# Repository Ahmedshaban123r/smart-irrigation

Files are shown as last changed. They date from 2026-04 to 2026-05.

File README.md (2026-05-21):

# An AI-Augmented Cyber-Physical Smart Precision Irrigation System

> **Course:** CIE-349 / CIE-408 — Embedded Systems (Spring 2026)
> **Institution:** Zewail City of Science and Technology
> **Program:** Communications and Information Engineering (CIE)
> **Repository status:** active development — see `STREAMS.md` for the team ↔ folder ↔ gate mapping.

---

## 1. Abstract

This repository contains the full engineering artefacts of a cyber-physical
precision-irrigation platform that couples real-time embedded control, networked
IoT telemetry, a cross-platform mobile human–machine interface, and on-device
computer-vision inference. The system continuously senses the soil-water,
electrical, thermal, and tank-level state of a two-plant test bench, performs a
safety-critical evaluation against a hysteresis-protected fault model, and
actuates a pump and a Cartesian gantry to deliver water on a per-plant basis.
A Raspberry Pi 4 attached to the same UART bus performs convolutional-neural-network
inference on plant images captured by a CSI camera, classifies disease state into
six clinical categories, and serialises both telemetry and inference results to a
Firebase Realtime Database (RTDB). A Flutter mobile client subscribes to the same
RTDB, rendering live sensor streams, AI detections, and an operator command surface
(pump toggle, gantry positioning, mode switching, emergency stop). The project
demonstrates the integration of MCU-class deterministic control, edge-class neural
inference, cloud-class persistence, and a touch-class user interface within a
single, gate-driven engineering process.

---

## 2. System Overview

| Subsystem | Hardware | Toolchain | Role |
|---|---|---|---|
| Real-time controller | PIC16F877A-I/P (8 MHz crystal) | MPLAB X IDE + XC8 v2.36 | Deterministic sensing, safety FSM, motion control, UART arbitration |
| Wi-Fi pump actuator | ESP8266 NodeMCU v3 | Arduino core, `Firebase_ESP_Client` | Wireless pump relay triggered by Firebase commands from the app / Pi |
| Edge AI + IoT gateway | Raspberry Pi 4 Model B (4 GB) | Python 3.11, `firebase-admin`, `pyserial`, TensorFlow Lite | Image capture, CNN inference, UART ↔ Firebase bridge |
| Cloud persistence | Firebase RTDB + Cloud Storage | Firebase JS/Admin SDK | Telemetry store, command queue, image hosting |
| Mobile HMI | Android / iOS | Flutter (Dart 3) + Material 3 | Dashboard, actuator control, AI monitor, alerts, voice command |
| Mechanical | Custom 3D-printed gantry | OpenSCAD source + STL | Linear motion, instrumentation mount, electronics enclosure |

> **Note on the actuator topology.** The pump can be driven through two
> independent paths. The **wired path** routes commands over UART
> (App → Firebase → Pi → PIC → relay on `RD0`) and is gated by the on-board
> safety FSM. The **wireless path** routes commands directly to an ESP8266
> NodeMCU that polls Firebase at `/esp/pump/state` and toggles its own relay
> on `D1` for a fixed 5-second cycle. Both paths can coexist on the same
> physical pump or drive separate solenoids; the ESP path is intended as a
> fast, low-latency override for app-initiated watering and for resilience
> when the Pi bridge is offline.

---

## 3. High-Level Architecture

```
┌──────────────────────────────────────────────────────────────────────────────┐
│                          PHYSICAL / ANALOG DOMAIN                            │
│                                                                              │
│  Soil moisture (cap.)   ACS712-05B   DHT11   HC-SR04   Limit SW   E-Stop SW  │
│        │                    │          │        │          │         │       │
│        ▼                    ▼          ▼        ▼          ▼         ▼       │
│   ┌────────────────────────────────────────────────────────────────────┐    │
│   │                       PIC16F877A (8 MHz)                           │    │
│   │   MCAL: ADC | GPIO | USART | TIMER0 | Interrupt Manager            │    │
│   │   HAL : Soil | Current | Humidity | Ultrasonic | LCD | LED | ...   │    │
│   │   APP : Safety FSM | Irrigation Sequencer | Comms | Main scheduler │    │
│   └────────────────────────────────────────────────────────────────────┘    │
│        │                    │                   │           │                │
│        ▼                    ▼                   ▼           ▼                │
│  Pump relay (12 V)     A4988 + NEMA17       Buzzer +     16×2 LCD            │
│  (wired path, RD0)     stepper gantry       LEDs                             │
└──────────────────────────────┬───────────────────────────────────────────────┘
                               │ UART 9600-8N1
                               │ (custom framed protocol, §6)
                               ▼
┌──────────────────────────────────────────────────────────────────────────────┐
│                       RASPBERRY PI 4 (edge gateway)                          │
│   capture_and_infer.sh  →  libcamera  →  TFLite (MobileNetV2 INT8)           │
│   pi_controller.py      :  serial RX/TX  ⇄  Firebase RTDB + Storage          │
└──────────────────────────────┬───────────────────────────────────────────────┘
                               │ HTTPS / WebSocket (Firebase SDK)
                               ▼
┌──────────────────────────────────────────────────────────────────────────────┐
│                       FIREBASE  (RTDB + Storage)                             │
│   /sensors  /status  /commands  /ai  /alerts  /esp/pump/state                │
└──────┬───────────────────────┬───────────────────────────────────────────────┘
       │ Firebase listener     │ 1 Hz poll on /esp/pump/state
       ▼                       ▼
┌─────────────────────────┐   ┌─────────────────────────────────────────────┐
│  FLUTTER MOBILE CLIENT  │   │           ESP8266 NodeMCU v3                │
│  (Android / iOS)        │   │   Wi-Fi → Firebase_ESP_Client                │
│  Landing → Dashboard →  │   │   D1 relay → wireless pump (5 s cycle,       │
│  Controls → AI Monitor  │   │            self-clears node on completion)   │
│  → Alerts (STT mic)     │   └─────────────────────────────────────────────┘
└─────────────────────────┘
```

**Two actuator paths to the pump:**

* **Wired path** — Flutter writes a `commands/pump` node → the Pi bridge
  consumes it → encodes a `0xBB 0x04` UART frame → PIC validates against the
  safety FSM → drives the relay on `RD0` for `PUMP_ON_TICKS × 100 ms`.
* **Wireless path** — Flutter writes `/esp/pump/state = "ON"` → the ESP8266
  picks it up within ≤ 1 s on its polling loop → energises its own relay on
  `D1` for `PUMP_ON_MS = 5000 ms` → resets the node to `"OFF"`.

---

## 4. Repository Layout

```
smart-irrigation/
├── pic-firmware/         PIC16F877A MPLAB X project (Stream A)
│   ├── MCAL/             Microcontroller-abstraction layer (ADC, USART, GPIO, TIMER0)
│   ├── HAL/              Hardware-abstraction layer (LCD, sensors, motor, relay, …)
│   ├── SERVICES/         Reusable services (STD_TYPES, BIT_MATH, Delay)
│   ├── APP/              Application layer (Safety, Comms, Irrigation, MyProject)
│   ├── include/          Cross-module headers (frame defs, pin maps)
│   ├── config.h          Central configuration (clock, thresholds, pin map, timing)
│   └── cmake/, _build/   Out-of-tree build helpers
│
├── esp-firmware/         ESP8266 NodeMCU pump actuator (Stream C)
│   └── esp.ino           Arduino sketch: Wi-Fi + Firebase polling + relay
│
├── pi-script/            Raspberry Pi bridge daemon (Stream B)
│   ├── pi_controller.py  UART ⇄ Firebase main bridge
│   ├── handshake.py      Boot-time handshake validator
│   ├── bidir_test.py     Loopback UART self-test
│   ├── test_firebase.py  RTDB connectivity test
│   ├── irrigation.service systemd unit (auto-start on boot)
│   └── export.json       RTDB schema snapshot (reference)
│
├── pi-ai/                Inference + camera layer (Stream B)
│   ├── Capture_camera/   libcamera capture + invocation script
│   ├── Irrigation system/Docker_files  Containerised inference runtime
│   ├── inference/        Daemon stubs (TFLite runner)
│   └── protocols/        Action-protocol packet generators
│
├── ml-pipeline/          Model training + export (Stream B)
│   ├── notebooks/Model (1).ipynb   MobileNetV2 fine-tune + INT8 quantisation
│   ├── dataset/          Dataset retrieval and augmentation scripts
│   └── models/           TFLite artefacts + label map + model card
│
├── flutter-app/          Mobile HMI (Stream C)
│   ├── lib/services/     firebase_service, stt_service, notification_service
│   ├── lib/screens/      Landing, Dashboard, Controls, AI Monitor, Alerts
│   ├── lib/widgets/      SensorCard, DetectionCard, StatusBadge, mic button, …
│   ├── lib/models/       protocol_definition.dart
│   ├── lib/theme/        Material 3 theme (greenDeep ↔ greenPale palette)
│   └── android/, ios/    Platform projects
│
├── mechanical/           CAD + STL artefacts (Stream D)
│   ├── cad/              OpenSCAD source (6 printed parts + assembly)
│   ├── stl/              Print-ready exports
│   └── print-settings/   Slicer profiles
│
├── Report and Feasibilty Study/  Course deliverables
├── app-release.apk       Latest Android build (for evaluator side-load)
├── default.hex           Latest PIC HEX (golden image)
├── README.md             ← this file
└── STREAMS.md            Team ↔ folder ↔ gate criteria mapping
```

---

## 5. PIC16F877A Firmware — Architecture

The firmware adopts a strict four-layer architecture inspired by AUTOSAR’s
classic separation of concerns. Each layer depends only on the layer immediately
below it, and inter-module access is mediated by explicit `*_interface.h`
contracts.

```
┌─────────────────────────────────────────────────────────────┐
│  APP/    Safety FSM · Irrigation sequencer · Comms · main  │
├─────────────────────────────────────────────────────────────┤
│  HAL/    LCD · Motor · Relay · Soil · Current · Humidity · │
│          Ultrasonic · LED · Buzzer · Button · Fan · Temp   │
├─────────────────────────────────────────────────────────────┤
│  MCAL/   ADC · USART · GPIO · TIMER0 · Interrupt Manager   │
├─────────────────────────────────────────────────────────────┤
│  SERVICES/  STD_TYPES · BIT_MATH · Delay                   │
└─────────────────────────────────────────────────────────────┘
```

### 5.1 Build configuration

| Parameter | Value |
|---|---|
| MCU | PIC16F877A-I/P (DIP-40) |
| Oscillator | HS, 8 MHz external crystal (with 22 pF load caps) |
| Compiler | Microchip XC8 v2.36 (free mode) |
| IDE | MPLAB X IDE v6.x |
| Programmer | PICkit 3 / PICkit 4 (ICSP) |
| Code memory used | see `_build/` after compilation |
| Power | 5 V regulated, common ground with relay-isolated 12 V rail |

Configuration fuses are declared at the top of `APP/MyProject.c`:
`FOSC=HS`, `WDTE=OFF`, `PWRTE=ON`, `BOREN=ON`, `LVP=OFF`, `CPD=OFF`,
`WRT=OFF`, `CP=OFF`. All build-time tunables live in `pic-firmware/config.h`
(thresholds, pin map, baud divisor, tick periods, microstep counts).

### 5.2 Scheduler model

`APP/MyProject.c` provides two co-existing top-level applications gated by
`#if` blocks:

* **Production main (`Section 1`)** — full pipeline. Cooperative super-loop
  with a 100 ms tick (`__delay_ms(100)`). Soft-real-time periods:
  * Sensor scan: every 2 s (`SENSOR_PERIOD_TICKS = 20`)
  * Auto irrigation cycle: every 5 min (`IRRIG_PERIOD_TICKS = 3000`)
  * Pi handshake gate at boot before entering the loop.
* **Debug main (`Section 2`)** — sensor + photo pipeline without the 5-min
  timer or handshake gate. The carriage bounces between plant 0 (3 cm from
  home) and plant 1 (13 cm). After each move the firmware reads every sensor,
  emits a `SENSORS` packet and an `AT_PLANT` packet, then idles 20 s while the
  Pi captures and uploads an image. Sensor pages are paged onto the LCD every
  4 s during the wait.

The two sections allow bring-up, debug, and demo without recompiling against
two different code trees.

### 5.3 Safety model

The `APP/Safety` module owns a per-channel hysteresis FSM with three states
per channel: **CLEAR → WARN → ACTION (locked)**. Each channel exposes an
independent set of thresholds in `config.h`:

| Channel | Sensor | Warn | Action | Clear | Action consequence |
|---|---|---|---|---|---|
| Soil over-saturation | Capacitive soil (RA0/AN0) | 80 % | 90 % | 75 % | Pump OFF + system lockout |
| Over-temperature | DHT11 (RB0) | 55 °C | 70 °C | 50 °C | Pump + stepper OFF, fan ON, lockout |
| Over-current | ACS712-05B (RA2/AN2) | 3 500 mA | 4 500 mA | 3 000 mA | Full actuator OFF + lockout |
| Dry-run (low tank) | HC-SR04 (RC3 trig / RB1 echo) | 5 cm | 2 cm | 6 cm | Pump OFF + lockout |

Visual / audible annunciation is bound to the FSM state: amber LED (RE1) and
buzzer (RB2) pulse in `WARN`; red LED (RE2) latches in `ACTION`. A lockout is
cleared only when *all* channels return to `CLEAR`.

**Command-priority arbitration** (highest to lowest):
`Safety lockout` ▶ `Hardware E-stop (RB4)` ▶ `App E-stop` ▶ `AI protocol` ▶
`App manual command` ▶ `Scheduled auto cycle`.

### 5.4 Motion control

`HAL/Motor` drives an A4988 stepper driver (1/16 microstepping, MS1/MS2/MS3
tied high externally) connected to a NEMA17 (JK42HS40) on a GT2 belt with a
20-tooth pulley. Calibration:

* 1 cm of linear motion = 800 microsteps
* Plant 0 at 4 000 steps (≈ 5 cm); plant 1 at 12 000 steps (≈ 15 cm)
* `STEP_DELAY_NORMAL_US = 1 800 µs` ⇒ a 10 cm traverse takes ≈ 14.4 s
* `STEP_DELAY_HOMING_US = 800 µs` for limit-switch approach

Homing routine: drive towards `RB3` limit switch at homing speed until the
switch trips (active-LOW, internal pull-up), back off by
`HOMING_BACKOFF_STEPS = 200` steps, and zero the logical position counter.

### 5.5 UART driver

`MCAL/USART` configures the EUSART for 9 600 baud, 8-N-1, BRGH = 1, asynchronous
mode. `UART_SPBRG_VAL = 51` is derived from `(F_OSC / (16 × baud)) − 1 =
(8e6 / 153 600) − 1 ≈ 51`, giving a steady-state error well under 1 %.

Frame parsing is centralised in `APP/Comms`, which exposes `Comms_Poll()` for
the super-loop and `Comms_SendSensors / Comms_SendStatus / Comms_SendAtPlant /
Comms_SendHandshakeAck` for outbound transmissions. See §6 for the wire
format.

### 5.6 Pin map (selected)

| MCU pin | Function | Direction |
|---|---|---|
| RA0 / AN0 | Capacitive soil moisture | Analog in |
| RA2 / AN2 | ACS712-05B current sense | Analog in |
| RB0 | DHT11 1-wire data | Bidirectional |
| RB1 | HC-SR04 echo | Digital in |
| RB2 | Buzzer (NPN driver) | Digital out |
| RB3 | Limit switch (active-LOW) | Digital in (pull-up) |
| RB4 | Emergency-stop button (active-LOW) | Digital in (pull-up) |
| RC0 | A4988 STEP | Digital out |
| RC1 | A4988 DIR (HIGH = away from home) | Digital out |
| RC2 | A4988 ENABLE (LOW = enabled) | Digital out |
| RC3 | HC-SR04 trigger | Digital out |
| RC4 | Cooling fan (NPN driver) | Digital out |
| RC6 / RC7 | UART TX / RX | Alt-function |
| RD0 | Pump relay (active-LOW) | Digital out |
| RD2 / RD3 / RD4-7 | LCD RS / EN / D4-D7 | Digital out |
| RE1 / RE2 | Amber / red LEDs | Digital out |

Full table in `config.h`.

---

## 6. UART Wire Protocol (PIC ↔ Raspberry Pi)

The link runs at 9 600-8-N-1 on `/dev/ttyAMA0` on the Pi side. Every frame
carries an explicit type byte so the receiver can dispatch without
context. Two header bytes distinguish direction.

### 6.1 Pi → PIC commands (fixed 3-byte frame)

```
┌────────┬────────┬────────┐
│ 0xBB   │  CMD   │  DATA  │
└────────┴────────┴────────┘
```

| `CMD` | Meaning | `DATA` semantics |
|---|---|---|
| `0x01` MODE | Set operating mode | `0x00` = AUTO, `0x01` = MANUAL |
| `0x02` IRRIGATE | Run one-shot irrigation on a single plant (manual) | plant index `0x00`–`0x04` |
| `0x03` ESTOP | App-driven emergency stop | `0x01` = stop, `0x00` = release |
| `0x04` PUMP | Direct pump command | high nibble = plant (0/1), low nibble = state (0 = OFF, 1 = ON) |
| `0x10` HANDSHAKE | Boot signal from Pi | `0xAA` |

### 6.2 PIC → Pi telemetry (variable-length frame)

```
┌────────┬────────┬──────────────── … ──────────────┐
│ 0xAA   │  TYPE  │              payload             │
└────────┴────────┴──────────────── … ──────────────┘
```

| `TYPE` | Payload | Meaning |
|---|---|---|
| `0x01` SENSORS | `soil, temp, hum, curr_hi, curr_lo, water` (6 B) | Periodic sensor snapshot (every 2 s) |
| `0x02` AT_PLANT | `plant_index` (1 B) | “Carriage parked, take a photo now” |
| `0x03` STATUS | `mode, lockout` (2 B) | Mode/lockout change notification |
| `0x10` HANDSHAKE | `0xBB` (1 B) | PIC acknowledges Pi handshake |

Current is transmitted as a 16-bit big-endian integer in milliamps; all other
fields are unsigned 8-bit. The frame definitions live in `pic-firmware/config.h`
and are mirrored in `pi-script/pi_controller.py`.

---

## 7. Raspberry Pi Bridge (`pi-script/`)

`pi_controller.py` opens the serial port, spawns a reader thread that decodes
framed packets into a Python dictionary, and forwards the result into the
Firebase paths described in §8. A second thread subscribes to the
`/commands/*` paths on Firebase, encodes commands into the 3-byte Pi → PIC
frame, and writes them to the serial port. The script also acts on the
`AT_PLANT` event by invoking `Capture_camera/capture_and_infer.sh`, which
takes a still via `libcamera-still`, runs the quantised MobileNetV2 model, and
uploads both the image and the inference result to Cloud Storage / RTDB.

The unit `pi-script/irrigation.service` registers the bridge with systemd so
it starts at boot and restarts on failure. `handshake.py` and `bidir_test.py`
are bring-up utilities; `test_firebase.py` verifies cloud credentials before
deployment.

---

## 8. ESP8266 Wireless Pump Actuator (`esp-firmware/`)

The ESP8266 NodeMCU v3 runs an Arduino sketch (`esp.ino`) that joins the
campus / hotspot Wi-Fi, signs into the same Firebase project used by the app
and the Pi, and polls a single RTDB node for pump commands.

| Aspect | Value |
|---|---|
| Board | ESP8266 NodeMCU v3 |
| Toolchain | Arduino IDE / Arduino CLI, ESP8266 core, `Firebase_ESP_Client` |
| Relay pin | `D1` (GPIO 5), active-LOW |
| Polled node | `/esp/pump/state` (string: `"ON"` / `"OFF"`) |
| Poll cadence | 1 Hz (`POLL_INTERVAL_MS = 1000`) |
| Pump-on duration | 5 s (`PUMP_ON_MS = 5000`) — matches `PUMP_ON_TICKS × 100 ms` on the PIC |
| Auto-clear | Node is reset to `"OFF"` after each cycle |
| Wi-Fi watchdog | Reconnect attempts on `WL_CONNECTED` loss (10 s budget) |
| Sources of commands | Flutter app (`Controls` tab) and the Pi bridge (forwarded from voice / scheduler) |

**Control flow:**

```
Flutter / Pi  ──set──▶  /esp/pump/state = "ON"
                                 │
                                 ▼
                        ESP8266 poll loop (1 Hz)
                                 │
                          state == "ON" ?
                                 │
                                 ▼
                  relay LOW → pump ON  (5 000 ms)
                                 │
                                 ▼
                  relay HIGH → pump OFF
                                 │
                                 ▼
                set /esp/pump/state = "OFF"  (idempotent latch)
```

**Build & flash:**

```bash
# Install ESP8266 board support + Firebase_ESP_Client library in the Arduino IDE
# Open esp-firmware/esp.ino
# Edit WIFI_SSID, WIFI_PASSWORD, API_KEY, DATABASE_URL to match your project
# Select board: NodeMCU 1.0 (ESP-12E Module), upload speed 115200, port = NodeMCU
# Sketch → Upload
```

**Security note.** The reference sketch stores Wi-Fi and Firebase credentials
as string literals for laboratory demonstration. For production deployment,
move secrets into a separate `secrets.h` excluded from version control and
enable Firebase RTDB rules that restrict `/esp/pump/state` to authenticated
writes.

---

## 9. Firebase RTDB Schema

```
sensors/
  current               float   (A)
  humidity              int     (%)
  soil_moisture_pct     int     (%)
  temperature           float   (°C)

status/
  gantry_x              int     (plant index)
  mode                  string  "AUTOMATIC" | "MANUAL"
  mode_changed_at       int     (ms epoch)
  pump                  string  "ON" | "OFF"
  system_state          string  "NORMAL" | "WARNING" | "FAULT"

commands/
  emergency_stop        bool
  pump/
    state               string  "ON" | "OFF"
    source              string  "app" | "voice"
    timestamp           int
  gantry_move/
    x                   int     (plant index)
    source              string
    timestamp           int
  cancel_ai_protocol    bool

ai/
  latest_detection/
    class               string  e.g. "Late_Blight"
    confidence          float   ∈ [0, 1]
    image_url           string  Cloud Storage URL
    timestamp           string  ISO-8601
  active_protocol/
    status              string  "idle" | "running"
    zone_x              int
    grace_remaining     int
  action_log/{id}/      class, confidence, action_taken, timestamp, zone_x

alerts/
  history/{id}/         message, severity, timestamp

esp/
  pump/
    state               string  "ON" | "OFF"   (consumed by the ESP8266 node)
```

`sensors/*` and `status/*` are read-only for the mobile client; all operator
actions are expressed as `commands/*` writes that the Pi bridge consumes.

---

## 10. Mobile Client (`flutter-app/`)

A Flutter (Dart 3) application targeting Android (primary, APK shipped) and
iOS. Architecture: a single `firebase_service.dart` exposes every read stream
as a static getter, so screens never construct database references directly.
The app is organised into five bottom-tab destinations:

| Tab | Screen | Responsibilities |
|-----|---|---|
| Home | `HomeScreen` | Landing surface, “how it works” cards, hero stats |
| Dashboard | `DashboardScreen` | Live `SensorCard` grid + `DetectionCard` |
| Controls | `ActuatorScreen` | Pump toggle, gantry move, emergency stop |
| AI Monitor | `AiMonitorScreen` | Latest detection image + active protocol state |
| Alerts | `AlertsScreen` | Severity-sorted alert history |

Cross-cutting services:

* `stt_service.dart` — singleton Speech-to-Text wrapper (Android requires
  `RECORD_AUDIO`).
* `notification_service.dart` — local notifications on fault / detection.
* `theme/app_theme.dart` — Material 3 theme, greenDeep → greenPale palette,
  DM Serif Display + DM Sans typography.

The AI model emits one of six classes; their colour mapping lives in
`DetectionCard._colorForClass`: `Healthy`, `Early_Blight`, `Late_Blight`,
`Pest`, `Nutrient_Deficiency`, plus a generic “unknown” fallback.

---

## 11. Machine-Learning Pipeline (`ml-pipeline/`)

| Aspect | Value |
|---|---|
| Base architecture | MobileNetV2 (TensorFlow / Keras) |
| Strategy | Transfer learning — ImageNet weights, last block fine-tuned |
| Input | 224 × 224 RGB |
| Output classes | 6 (`healthy`, `leaf_spot`, `blight`, `pest`, `wilt`, `nutrient_deficiency`) |
| Loss | Categorical cross-entropy |
| Optimiser | Adam, learning-rate scheduled |
| Augmentation | Random flip, rotation, brightness, zoom |
| Target accuracy | ≥ 92 % (test) / ≥ 90 % (post-INT8 quantisation) |
| Export format | TensorFlow Lite, INT8 post-training quantisation |
| Target inference time | < 200 ms on Raspberry Pi 4 (single thread) |
| Notebook | `ml-pipeline/notebooks/Model (1).ipynb` |
| Artefacts | `ml-pipeline/models/mobilenetv2_int8.tflite`, `labels.txt`, `model_card.md` |

The notebook produces a full evaluation: training curves, per-class precision
/ recall, confusion matrix, and a quantisation-aware delta report.

---

## 12. Mechanical Subsystem (`mechanical/`)

The gantry is a single-axis linear stage executed in 3D-printed PLA on an
aluminium 2020 V-slot frame. Six OpenSCAD parts compose the assembly:

| Part | File | Function |
|---|---|---|
| 1 | `Part1_Drive_End_Bracket.scad` | Mounts the NEMA17, anchors the GT2 belt, terminates the 8 mm smooth rod |
| 2 | `Part2_Idler_End_Bracket.scad` | Houses the idler pulley + tensioner |
| 3 | `Part3_Carriage_Plate.scad` | LM8UU bearing carriage carrying the watering manifold + camera |
| 4 | `Part4_Belt_Clamp_x2.scad` | Pair of GT2 belt clamps for the carriage |
| 5 | `Part5_Control_Box.scad` | Electronics enclosure (PIC, A4988, relay, LCD bezel) |
| 6 | `Part6_Rod_End_Holder_x2.scad` | Twin rod-end clamps |

The full assembly is rendered in `mechanical/cad/irrigation_assembly.scad`.

**Frame BOM:** 2 × 500 mm 2020 V-slot extrusion, 1 × 8 mm linear rod, 2 ×
LM8UU linear bearings, GT2 belt + 20 T pulley, NEMA17 stepper.

---

## 13. Build, Flash, and Run

### 13.1 PIC firmware

```bash
# In MPLAB X IDE
File → Open Project → pic-firmware (CMake project) or use the .X folder
Select tool: PICkit 3 / 4 (ICSP)
Build → Make and Program Device
```

The golden HEX is checked in at `default.hex` for evaluators without a build
toolchain.

### 13.2 Raspberry Pi bridge

```bash
cd pi-script
sudo apt install python3-pip
pip install pyserial firebase-admin --break-system-packages

# One-shot run
python3 pi_controller.py

# Permanent install
sudo cp irrigation.service /etc/systemd/system/
sudo systemctl daemon-reload
sudo systemctl enable --now irrigation
```

Edit `pi_controller.py` to point `FIREBASE_CRED`, `FIREBASE_DB_URL`, and
`FIREBASE_BUCKET` at your project, then drop the service-account JSON at the
path given by `FIREBASE_CRED`.

### 13.3 ESP8266 firmware

```bash
# Arduino IDE: Board Manager → install "esp8266" core
# Library Manager → install "Firebase Arduino Client Library for ESP8266 and ESP32"
# Open esp-firmware/esp.ino, edit the credential macros, then Upload.
# Or via Arduino CLI:
arduino-cli compile --fqbn esp8266:esp8266:nodemcuv2 esp-firmware/esp.ino
arduino-cli upload  --fqbn esp8266:esp8266:nodemcuv2 -p COMx esp-firmware/esp.ino
```

### 13.4 Inference layer

```bash
cd pi-ai/Capture_camera
chmod +x capture_and_infer.sh
./capture_and_infer.sh                # one-shot capture + classify + upload
```

The Docker variant under `pi-ai/Irrigation system/Docker_files` provides a
reproducible runtime if Pi OS package versions drift.

### 13.5 Mobile client

```bash
cd flutter-app
flutter pub get
flutter run                # debug, attached device
flutter build apk          # release APK
flutter analyze            # static analysis
flutter test               # unit + widget tests
```

`lib/firebase_options.dart` is generated locally with `flutterfire configure`
and is git-ignored.

### 13.6 ML training

```bash
cd ml-pipeline
pip install -r requirements.txt
jupyter notebook "notebooks/Model (1).ipynb"
```

---

## 14. Hardware Bill of Materials (selected)

| Block | Component | Notes |
|---|---|---|
| MCU | PIC16F877A-I/P | 8 MHz HS crystal + 2 × 22 pF |
| Wi-Fi node | ESP8266 NodeMCU v3 + 5 V relay module on `D1` | Shares Firebase project with the Pi |
| Edge AI | Raspberry Pi 4 Model B (4 GB) + Pi Camera v2 | Active cooling recommended |
| Sensors | Capacitive soil v1.2, DHT11, ACS712-05B, HC-SR04 | All 5 V tolerant |
| Actuation | NEMA17 (JK42HS40), A4988 driver, 12 V DC pump, 2-ch SRD relay | Common ground with logic |
| HMI | 16×2 HD44780 LCD (4-bit), amber + red LEDs, buzzer, momentary E-stop | RD-port shadowed in firmware |
| Frame | 2 × 2020 V-slot 500 mm, 8 mm rod, LM8UU, GT2 belt + 20 T pulley | See §11 |
| Power | 12 V / 5 A SMPS + LM7805 logic rail | Isolated relay coil |

A full BOM with vendor links is included in `Report and Feasibilty Study/`.

---

## 15. Course Milestones

| Gate | Criterion | Target |
|---|---|---|
| G0 | Development environment ready, repo cloned, tool-chain reproducible | End of Week 1 |
| G1 | All four ADC channels validated to ±5 %, safety FSM trips at the configured thresholds, ML training pipeline producing ≥ 92 % test accuracy | End of Week 2 |
| G2 | Each subsystem (PIC, Pi, App) runs standalone; bidirectional UART + Firebase + APK build all green | End of Week 3 |
| G3 | Full closed loop verified: App ↔ Firebase ↔ Pi ↔ PIC ↔ actuator ↔ telemetry ↔ App; safety overrides on every layer | End of Week 4 |
| G4 | Demo bench, photos, video, final report | End of Week 5 |
| Live demo | Departmental defence | 17 – 21 May 2026 |
| Final submission | Course portal upload | Day of the final exam |

Per-stream gate ownership and mitigation paths are tabulated in
`STREAMS.md`.

---

## 16. References

1. Microchip Technology, *PIC16F87XA Data Sheet*, DS39582.
2. Allegro MicroSystems, *ACS712 Fully Integrated, Hall-Effect-Based Linear
   Current Sensor IC*, datasheet.
3. Allegro MicroSystems / Pololu, *A4988 Stepper Motor Driver Carrier*,
   reference design.
4. Aosong Electronics, *DHT11 Humidity & Temperature Sensor* datasheet.
5. Sandler, M., Howard, A., Zhu, M., Zhmoginov, A., Chen, L.-C.,
   *MobileNetV2: Inverted Residuals and Linear Bottlenecks*, CVPR 2018.
6. Google, *TensorFlow Lite — Post-Training Integer Quantization*, official
   guide.
7. Google, *Firebase Realtime Database — Data Organization*, official
   documentation.
8. Flutter Authors, *Flutter Engineering Best Practices*, flutter.dev.
9. AUTOSAR Consortium, *Layered Software Architecture* (motivation for the
   MCAL / HAL / SERVICES / APP split adopted in `pic-firmware/`).

---

## 17. License

Released under the MIT License. See `LICENSE` if present, otherwise
distribute under the terms reproduced in the course handbook.

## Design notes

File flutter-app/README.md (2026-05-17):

# Irriga

A smart irrigation mobile app built with Flutter and Firebase, designed for real-time monitoring and control of an AI-powered plant care system.

---

## What It Does

Irriga connects to a hardware system (Raspberry Pi + sensors) via Firebase Realtime Database. It gives you live visibility into your plants health and lets you control irrigation by touch or by voice.

- **Live sensor dashboard** — soil moisture, temperature, water level, and current draw, each with a sparkline history chart
- **AI plant monitoring** — displays the latest camera detection (plant class + confidence score) from the edge device
- **Voice commands** — say "pump on", "water for 30 seconds", or "emergency stop" and the system responds
- **AI protocol lifecycle** — when a disease or pest is detected, the app automatically starts the irrigation protocol with a live countdown timer
- **Local notifications** — get alerted when a plant issue is detected or when manual mode is activated
- **Alert history** — a log of all system events sorted newest first
- **Manual / Automatic mode** — switch between full manual control and AI-driven automation

---

## Tech Stack

| Layer | Technology |
|---|---|
| Mobile app | Flutter (Dart) |
| Database | Firebase Realtime Database |
| Storage | Firebase Storage |
| Notifications | flutter_local_notifications |
| Voice | speech_to_text |
| Charts | fl_chart |
| Logging | logger |

---

## App Structure

```
lib/
├── main.dart                    # App entry, Firebase init, navigation
├── screens/
│   ├── home_screen.dart         # Landing page
│   ├── dashboard_screen.dart    # Live sensor grid + offline banner
│   ├── actuator_screen.dart     # Pump, gantry, emergency stop controls
│   ├── ai_monitor_screen.dart   # Detection image, active protocol, action log
│   └── alerts_screen.dart       # Alert history
├── services/
│   ├── firebase_service.dart    # All RTDB streams and write helpers
│   ├── notification_service.dart # Local notifications + alert logging
│   └── stt_service.dart         # Speech-to-text wrapper
├── utils/
│   ├── command_parser.dart      # Voice command parsing (pure, fully tested)
│   └── app_logger.dart          # Structured logger
├── models/
│   └── protocol_definition.dart # Per-class irrigation durations and actions
└── widgets/
    ├── sensor_card.dart          # Live value + sparkline
    ├── stt_mic_button.dart       # FAB mic with feedback bubble + command guide
    ├── detection_card.dart       # AI detection display
    ├── mode_toggle_card.dart     # Auto/Manual toggle
    └── status_badge.dart         # System state pill
```

---

## Voice Commands

Long-press the mic button in the app to see the full command reference. Examples:

| Say | Action |
|---|---|
| "pump on" | Turn irrigation pump ON |
| "pump off" | Turn irrigation pump OFF |
| "water for 45 seconds" | Run irrigation cycle for 45s |
| "gantry x 200" | Move gantry to position 200mm |
| "emergency stop" | Stop all actuators immediately |
| "cancel AI" | Cancel the active AI protocol |

---

## Firebase Data Structure

```
/sensors
  soil_moisture       read    % moisture
  temperature         read    degrees C
  water_level         read    % level
  current             read    Amps

/status
  pump                read    ON / OFF
  system_state        read    NORMAL / WARNING / FAULT
  mode                write   AUTOMATIC / MANUAL
  gantry_x            read    current position mm

/ai
  latest_detection    read    { class, confidence, image_url, timestamp }
  active_protocol     write   { status, triggered_class, deadline_ms }
  action_log          read    history of AI actions

/commands
  pump                write   { state, timestamp, source }
  gantry_move         write   { x, timestamp, source }
  emergency_stop      write   true
  irrigation_cycle    write   { duration, timestamp, source }

/alerts
  history             write   { message, severity, timestamp }
```

---

## Getting Started

### Prerequisites

- Flutter SDK 3.x
- Firebase project with Realtime Database and Storage enabled
- `lib/firebase_options.dart` generated via `flutterfire configure`

### Run

```bash
flutter pub get
flutter run                   # Android device
flutter run -d chrome         # Chrome (web — no push notifications)
flutter build apk --release   # Production APK
```

### Tests

```bash
flutter test test/command_parser_test.dart
```

---

## Hardware Integration

The app is designed to pair with a Raspberry Pi that:

1. Captures images with a camera module
2. Runs a plant disease classification model
3. Writes detections to Firebase under `ai/latest_detection`
4. Reads commands from `commands/` and controls physical actuators

The app handles protocol management, notifications, and UI automatically once detections arrive.

---

## Project Status

Currently in active development as part of a university embedded systems project. Hardware integration in progress.

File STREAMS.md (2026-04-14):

# Stream ↔ Folder Mapping

This file maps each execution stream to its primary repository folder(s),
the responsible member(s), and the relevant gate criteria.

---

## Stream A — Hardware + Safety (M1 + M2)

**Folders:** `pic-firmware/`

| Sub-folder | Contents | Owner |
|---|---|---|
| `pic-firmware/src/` | `.c` source files — ADC scan, safety FSM, UART ISR, motion control, LCD, keypad | M1 + M2 |
| `pic-firmware/include/` | `.h` header files — pin definitions, thresholds, structs | M1 + M2 |
| `pic-firmware/mplab-project/` | MPLAB X project files (`.X` directory, `Makefile`) | M2 |

**Gate responsibilities:**
- G1: All 4 ADC channels ±5%, safety features fire at correct thresholds
- G2: UART frames sent/received, command priority engine working
- G3: Full app + AI command loop verified, safety blocks both

---

## Stream B — ML + AI Actuation (M3)

**Folders:** `pi-ai/`, `ml-pipeline/`

| Sub-folder | Contents | Owner |
|---|---|---|
| `pi-ai/inference/` | `daemon.py`, `preprocess.py`, `capture.py` | M3 |
| `pi-ai/protocols/` | `action_protocol.py` — generates 8-byte UART packets from inference output | M3 |
| `pi-ai/systemd/` | `irrigation-ai.service` systemd unit file | M3 |
| `ml-pipeline/notebooks/` | `train_mobilenetv2.ipynb` — full training, evaluation, confusion matrix | M3 |
| `ml-pipeline/dataset/` | Dataset download scripts, label mapping, augmentation pipeline | M3 |
| `ml-pipeline/models/` | `mobilenetv2_int8.tflite`, `labels.txt`, `model_card.md` | M3 |

**Gate responsibilities:**
- G1: Training complete, ≥92% test accuracy
- G2: TFLite model on Pi generates correct action protocol packets
- G3: Pi → PIC UART link tested, all 6 protocols end-to-end

**HuggingFace:** Model + dataset + notebook pushed by G4. Cite in README.

---

## Stream C — IoT + Mobile App (M4)

**Folders:** `esp-firmware/`, `flutter-app/`

| Sub-folder | Contents | Owner |
|---|---|---|
| `esp-firmware/src/` | `main.cpp`, `firebase.cpp`, `uart_bridge.cpp`, `spiffs_buffer.cpp` | M4 |
| `esp-firmware/include/` | `config.h` (WiFi creds template), `frame_defs.h` | M4 |
| `flutter-app/` | Full Flutter project — `lib/`, `pubspec.yaml`, `android/`, `ios/` | M4 |

**Gate responsibilities:**
- G1: ESP pushes JSON to Firebase, reads commands
- G2: Bidirectional firmware — SPIFFS buffer, ACK/NACK handler
- G3: Full app → Firebase → ESP → PIC → actuator → ACK → app loop verified
- G4: Release APK built and uploaded

**UART protocol note:** M4 must agree with M2 on frame format by **end of Week 1**.
Reference: `pic-firmware/include/frame_defs.h` (M2 owns this file — M4 mirrors it in `esp-firmware/include/frame_defs.h`).

---

## Stream D — 3D Design + Mechanical (M5)

**Folder:** `mechanical/`

| Sub-folder | Contents | Owner |
|---|---|---|
| `mechanical/cad/` | OpenSCAD source files (`.scad`) for all 6 printed parts | M5 |
| `mechanical/stl/` | Print-ready STL exports | M5 |
| `mechanical/print-settings/` | Slicer profiles (`.3mf` or `.ini`), print settings table | M5 |

**Gate responsibilities:**
- G1: All STLs exported, parts ordered
- G2: Control box and gantry brackets printed and test-fitted
- G3: Gantry fully assembled, wiring harness built, electronics mounted
- G4: Demo photos + video recorded and uploaded

---

## Cross-Stream Dependencies (Critical Path)

| Dependent | Depends On | By Gate | Mitigation |
|---|---|---|---|
| `pi-ai/` UART link | `pic-firmware/` UART ISR | G2 | Use USB-serial stub until M2 is ready |
| `esp-firmware/` frame parsing | `pic-firmware/` frame format | G1 | M2 + M4 agree on `frame_defs.h` by Week 1 |
| App → PIC command test | ESP + PIC UART working | G2 | Test with ESP-only loopback |
| `mechanical/` final mount | All electronics stable | G3 | Use dummy boards for fitment in Weeks 2–3 |

---

## Commit Convention

```
[stream-a] Add safety FSM for dry-run protection
[stream-b] Add TFLite INT8 export script
[stream-c] Wire Firebase RTDB schema
[stream-d] Add carriage plate OpenSCAD v2
[docs]     Update BOM with 1-axis redesign
```

Use `[stream-a]` through `[stream-d]` prefixes so commits are filterable by stream.

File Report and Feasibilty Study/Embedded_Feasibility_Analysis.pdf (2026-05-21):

# Feasibility Analysis: Scaling AI-Based Precision Irrigation from Laboratory Prototype to Field Deployment

## Feasibility Analysis Report - CIE-349/408 Embedded Systems

Ahmed Shaban
ID: 202200217

Abdullah Ahmed
ID: 202200206

Ahmed Abdullah
ID: 202202017

Ibrahim Hany
ID: 202200518

Khaled Mahmoud
ID: 202200282

Abstract—This paper presents a feasibility analysis for scaling a 1-axis laboratory prototype of an AI-based Smart Precision Irrigation System into a 2D agricultural field deployment. The initial prototype successfully integrates edge AI (MobileNetV2 via Raspberry Pi), real-time control (PIC16F877A), and IoT connectivity (ESP8266 to Firebase). However, scaling the mechanical gantry structure to a multi-meter field matrix introduces severe structural and electrical bottlenecks. This report proposes transitioning from a mechanical water-delivery gantry to a distributed IoT sensor network paired with a zone-based solenoid fluidic system. Environmental viability and a complete cost analysis (BOM) for a pilot deployment are also detailed, demonstrating that the revised architecture is highly feasible and economically viable at approximately 9,020 EGP.
Index Terms—Smart Irrigation, Precision Agriculture, Edge AI, IoT, Feasibility Analysis, Embedded Systems.
I. INTRODUCTION

The core cyber-physical loop of the Smart Precision Irrigation System has been successfully validated in a laboratory environment. The system senses local parameters, captures crop images, utilizes a quantized TFLite model to classify plant health (e.g., Healthy, Blight, Pest), and drives a NEMA 17 stepper motor to physically move a water nozzle to the target location along a 1-axis aluminum extrusion rail. While the computational architecture and the UART/MQTT communication bridges operate flawlessly, extrapolating the 1-axis mechanical design (using 2020 aluminum extrusions and 8 mm smooth rods) to a large 2D field deployment poses significant mechanical, electrical, and economic challenges. This report analyzes these constraints and formalizes the engineering pivots required to deploy the system in a realworld greenhouse or agricultural plot.

II. TECHNICAL FEASIBILITY AND REQUIRED ARCHITECTURAL PIVOTS

A. Mechanical vs. Fluidic Distribution
Constraint: Moving from a 1-axis slider to a 2D matrix requires building a full X-Y gantry system. A 2020 aluminum extrusion and an 8 mm smooth rod cannot span distances greater than 1 to 1.5 meters without experiencing severe deflection (sagging) under their own weight. Adding the payload of a water-filled hose, a Raspberry Pi 4, and camera equipment will cause linear bearings (LM8UU) to bind. Furthermore, the required holding torque exceeds the capabilities of standard NEMA 17 motors, and timing belts will suffer from stretching and skipped teeth over long spans.
Architectural Pivot: The system must eliminate the physical transportation of the water source.
- Zone-Based Drip Irrigation: Stationary PVC pipes and drip lines should be laid across the field, divided into independent irrigation zones.
- Solenoid Valves: The NEMA 17 motors and gantry mechanism will be replaced by 12V DC Solenoid Water Valves at the head of each zone. The central PIC16F877A controller will trigger relays to open specific valves based on AI or sensor-driven protocols.
B. Sensing and Power Distribution
Constraint: The current prototype utilizes a single DHT11 sensor and local analog soil moisture sensors. Running 5V or 12V DC lines across a 20+ meter field to power sensors will result in significant voltage drop, rendering analog readings highly inaccurate. Furthermore, the DHT11 is strictly intended for indoor use and will fail under field condensation and dust. Architectural Pivot: Distributed Wireless Nodes.
- Soil Nodes: Deploy individual ESP8266 microcontrollers at each irrigation zone. Each node will locally read its capacitive soil moisture sensor and transmit the data back to the central hub via a wireless mesh or a robust RS-485 wired bus.
- Weatherproofing: The environmental sensor must be upgraded to an industrial-grade SHT3x or BME280 sensor, housed within a 3D-printed sintered radiation shield.
C. Edge AI Vision (The Mobile Component)
Since water delivery is now stationary, the Raspberry Pi 4 and Pi Camera must still monitor the crops to execute the MobileNetV2 classifications.
Architectural Pivot: Mount the vision system on an overhead zipline, a drone, or an automated ground rover. This mobile agent operates purely for imaging, pushing detection coordinates and protocol IDs (0x01 to 0x05) to the Firebase RTDB, allowing the stationary fluidics to actuate accordingly.

III. ENVIRONMENTAL AND MATERIAL FEASIBILITY
Standard 3D-printed PLA parts (used in the laboratory prototype) undergo a glass transition at approximately 60◦C. In direct Egyptian sunlight, ambient temperatures inside enclosures will easily exceed this, causing catastrophic warping and structural failure.
All outdoor mechanical mounts and electronic enclosures must be printed using Polyethylene Terephthalate Glycol (PETG) or Acrylonitrile Styrene Acrylate (ASA), both of which offer superior UV resistance and thermal stability. The central control unit housing the PIC and relays must be placed in an off-the-shelf IP65/IP67 rated waterproof enclosure with properly sealed PG7 cable glands.

IV. COST ANALYSIS
The following Bill of Materials (BOM) outlines the estimated costs for scaling the system to a 4-Zone Pilot Deployment in the Egyptian market. The cost of the massive aluminum field gantry is omitted due to the adoption of the fluidic pivot.

TABLE I
ESTIMATED BOM FOR 4-ZONE PILOT DEPLOYMENT
Subsystem | Component | Qty | Total (EGP)
Control Hub | PIC16F877A (Existing) | 1 | 0
| ESP8266 NodeMCU | 1 | 200
| IP65 Waterproof Enclosure | 1 | 350
| 12V 30A Power Supply | 1 | 600
| 4-Channel 5V Relay | 1 | 120
Fluidics | 0.5 HP AC Water Pump | 1 | 2,200
| 1/2” 12V Solenoid Valve | 4 | 800
| PVC Pipes & Drip Lines | Lot | 800
Sensing | ESP8266 (For nodes) | 4 | 800
| Capacitive Soil Sensor | 4 | 200
| ACS712 Current Sensor | 5 | 400
| SHT30 Temp/Hum Sensor | 1 | 250
Vision (AI) | Raspberry Pi 4 + Camera | 1 | 0
Mechanics | PETG 3D Printing (∼200g) | Lot | 800
| Rover/Zipline Chassis Kit | 1 | 1,500
Total | Estimated Cost | ∼9,020
V. CONCLUSION
Scaling the Smart Precision Irrigation System is highly feasible both technically and economically. By decoupling the AI computer vision (rover/camera) from the fluidics (stationary pumps and solenoid valves), the system eliminates the mechanical impossibility of a multi-meter gantry. This updated architecture remains robust against agricultural environments while preserving the sophisticated software, safety logic, and machine learning pipelines developed in the laboratory phase.

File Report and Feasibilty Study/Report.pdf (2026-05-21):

# AI-Based Smart Precision

# Irrigation System with Safety-Critical Control

Final Project Report

CIE-349 / CIE-408 Embedded Systems

Zewail City, University of Science and Technology

Program of Communications and Information Engineering

Spring 2026

Supervisors

Dr. Hazem Fahmy | · Eng. George Maximous
Eng. Zaynap Ahmed | · Eng. Yasser Deif

Team Members

Khaled Mahmoud Abdel Sayed Eldadr | 202200282
Ibrahim Hany Ibrahim Eldosoky Ahmed Hanafy | 202200518
Abdullah Ahmed Sayed Abdel Samiee Mohamed | 202200206
Ahmed Shaban Gaballah Hassan | 202200217
Ahmed Abdullah Abdelaziz Almuhanna | 202202017

github.com/Ahmedshaban123r/smart-irrigation

CIE-349 / CIE-408 Smart Precision Irrigation System | Spring 2026

Contents

1 Introduction and Literature Review | 2
2 System Components and Bill of Materials | 3
3 System Architecture | 4
4 Safety-Critical Features Pseudocode | 6
5 PIC16F877A Pin Conguration | 8
6 Software Architecture | 9
7 Machine Learning Pipeline | 11
8 Mechanical Design Summary | 13
9 Integration, Testing, and Results | 13
10 Conclusion | 14

1. Introduction and Literature Review
1.1. Problem Statement
Conventional irrigation systems in small-scale agriculture and indoor cultivation suer from three persistent ineciencies: water wastage due to uniform scheduling regardless of soil state, plant stress caused by delayed detection of disease or pest infestation, and safety hazards arising from unmonitored pump operation (dry-running, electrical faults, overheating). These problems are especially acute in resource-constrained regions where water conservation is critical and where access to agricultural expertise is limited.
This project addresses these issues by designing and implementing a cyber-physical smart precision irrigation system that integrates real-time embedded control, IoT-style cloud connectivity, on-device machine-learning-driven plant diagnostics, and safety-critical fault management into a single coherent platform. The system delivers targeted irrigation to a linear row of plants, autonomously detects plant disease and pest presence via computer vision, and enforces hard safety guarantees through a deterministic priority engine running on a real-time microcontroller.
1.2. Literature Review
Smart irrigation has been studied extensively over the past decade. Early work focused on threshold-based systems using single soil-moisture sensors connected to relay-driven solenoid valves; these systems lack adaptivity and provide no diagnostic feedback. Later research introduced wireless sensor networks (WSNs) with cloud telemetry, improving observability but oering no closed-loop intelligence at the plant level. More recent work incorporates deep-learning plant disease classication using architectures such as ResNet, EcientNet, and MobileNet on datasets like PlantVillage but most published systems run inference on cloud servers, introducing latency and connectivity dependence unsuitable for eld deployment.
The novelty of this project lies in three integration choices that dierentiate it from prior art:
1. On-device inference using a quantized MobileNetV2 (TFLite INT8) running locally on a Raspberry Pi 4, eliminating cloud dependency for vision-based decisions.
2. A layered real-time architecture with strict separation between the safety-critical control plane (PIC16F877A) and the high-level cognitive/UI plane (Raspberry Pi), enforced by a deterministic priority hierarchy.
3. A minimal-scope IoT bridge the ESP8266 is dedicated solely to pump-state synchronization, reecting a deliberate engineering tradeo to maximize reliability of the safety-critical actuator path rather than overloading a single Wi-Fi module with full bidirectional bridging.
1.3. System Objectives
1. Deliver targeted irrigation to individual plants along a 1-axis linear gantry with positioning accuracy better than ±2 mm.
2. Achieve plant disease classication accuracy above 92% across six target classes using on-device inference at under 200 ms per frame.
3. Enforce four independent safety-critical features with deterministic two-level (warning → action) response under 200 ms.
4. Provide a mobile interface (hosted via the Raspberry Pi) for monitoring, scheduling, and manual override, with end-to-end command latency under 3 seconds.

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

Category | Component | Specication | Role
Belt drive | GT2 belt + 20T pul- ley + idler | 6 mm wide | Linear actuation
Power | 12 V 3 A regulated PSU | 2.1 mm barrel | Primary supply
Regulators | LM7805 | +
| AMS1117-3.3V
TO-220 | +
| | SOT-223 | 5 V & 3.3 V rails
2.2. Input/Output Diagram (High-Level)

+ - - - - - - - - - - - - - - - - - - - - - - - - - - - - - - - - - - - - - - - - - - - - - -+
| | USER INTERFACE LAYER | |
| | Flutter App ( hosted by Pi ) | |
| | LCD 1602 | | | 4 x4 Keypad | |
+ - - - - - - - -+ - - - - - - - - - - - - - - - - -+ - - - - - - - - -+ - - - - - - - - -+
| HTTP / WS | | | |
v | v | v
+ - - - - - - - - - - - - - -+ | + - - - - - - - - - - - - - - - - - - - - - - - - - - - - - - - - - - - - - - - -+
| | Pi Camera | | - - >| | Raspberry Pi 4 ( HOST ) | |
| | OV5647 | | | | | App backend + Firebase sync | |
+ - - - - - - - - - - - - - -+ | | | TFLite INT8 ML inference | |
| | Orchestrates capture -> infer -> act | |
+ - -+ - - - - - - - - - - - - - - - - - - - - - - -+ - - - - - - - - - - - - - -+
| UART 0 xBB ( AI cmds ) | | Firebase RTDB
| UART 0 xCC ( App cmds ) | | / pump_state
v | v
+ - - - - - - - - - - - - - - - - - - - - - - - - -+ | + - - - - - - - - - - - - -+
| | PIC16F877A | | | | | ESP8266 | |
| Safety + Control Core | | | | Pump - state | |
| ( Priority Engine ) | | | | | bridge | |
+ - -+ - - - - - - - -+ - - - - - - - - -+ - - -+ | + - - - - - -+ - - - - - -+
| ADC | | Digital | STEP | | Digital
v | v | v | v
+ - - - - - - -+ + - - - - - -+ + - - - - - - - - -+ | + - - - - - - - - -+
| Sensors | | LCD | | | Stepper | | | | RELAY | | - - > Pump
| 4 ch | | | Keypad | | DRV8825 | | | module | |
+ - - - - - - -+ + - - - - - -+ + - - - - - - - - -+ | + - - - - - - - - -+
3. System Architecture
3.1. Layered Architecture
The system follows a layered architecture with strict separation of concerns. The Raspberry Pi serves as the central host for both the AI pipeline and the application backend, while the ESP8266 is reduced to a dedicated pump-relay bridge a narrow, single-purpose role that improves reliability of the most safety-relevant actuator path.

Layer 1 Physical Sensing and Actuation
Four analog sensors (soil moisture, temperature, current, ultrasonic water level), the stepperdriven linear carriage, the relay-switched water pump, LCD, keypad, LEDs, buzzer, and the homing limit switch. All connected to PIC16F877A I/O pins, except the relay which is wired to the ESP8266.

Layer 2 Real-Time Control (PIC16F877A)
Executes a 100 ms main control loop. Owns ADC scanning, the four safety state machines, motion control with acceleration ramps, the command priority arbitration engine, and UART communication to the Pi. Final authority on all safety decisions.

Layer 3 Pump-State Bridge (ESP8266)
Single dedicated function. Connects to Wi-Fi, subscribes to a single Firebase RTDB key (/pump_state), and drives the pump relay GPIO accordingly (HIGH/LOW). Has no UART link to the PIC; does not see telemetry, AI commands, or app commands. This minimalism is deliberate the ESP becomes a dumb actuator gateway with predictable behavior.

Layer 4 Host & AI (Raspberry Pi 4)
The heart of the system. Hosts the Flutter app backend (web server + Firebase sync), runs the TFLite inference daemon, orchestrates the capture → infer → act pipeline, communicates with the PIC over UART for motion and safety telemetry, and writes /pump_state to Firebase to indirectly control the pump via the ESP.
3.2. Why the ESP8266 Is Pump-Only
The original design considered using the ESP as a full bidirectional bridge for all telemetry, commands, and AI packets. This was rejected for three reasons:
1. Reliability concentration. The pump is the only actuator that can cause irreversible harm (root rot from overwatering, re from dry-run). Isolating its control on a dedicated MCU with no other duties means the pump relay path cannot be starved by network or UART parsing load.
2. Pi already has Wi-Fi. The Raspberry Pi 4 has onboard Wi-Fi and a full networking stack. Routing all telemetry through the ESP would be redundant.
3. Reduced UART contention. The PIC's single USART now carries only direct PIC↔Pi trac (motion commands, telemetry, safety status).
3.3. Priority Hierarchy (Hard Rule)

A single immutable priority order governs all actuator commands at the PIC:

Safety Lockout (highest) > AI Action Protocol > Mobile App Command > Scheduled Irrigation (lowest)

The Command Priority Engine on the PIC is the sole arbiter. A lower-priority command never preempts a higher-priority lockout state. When a safety lockout is active, all incoming commands are rejected with a NACK frame containing a reason code, and the PIC asserts a pump force-o by writing the pump-state path on the Pi side.

3.4. Signal Flow Block Diagram

+ - - - - - - - - - - - - - - - - - - - - - - - - - - - - - - - - - - - - - - - - - - - - - - - - - - - - - - - - - - - - - - - -+
| | | LAYER 4 -- Raspberry Pi 4 ( HOST ) | | |
| | [ Pi Camera ] -> [ Preprocess 224 x224 ] -> [ MobileNetV2 INT8 ] | |
| | | [ Action Protocol Generator ] | | |
| | + - - - - - - - - - - - - - - - - - - - - - - - - - - - - - - - - - - - - - - - - - - - -+ | |
| | | | Flask / FastAPI backend + Firebase client | | | |
| | | | Flutter web app served on Pi port 80 | | | |
| | + - - - - - - - - - - - - - - - - - - - - - - - - - - - - - - - - - - - - - - - - - - - -+ | |
+ - - - - -+ - - - - - - - - - - - - - - - - - - - - - - - - - - - - - - - - - - - - - - -+ - - - - - - - - - - - - - - - - - -+
| UART 0 xBB / 0 xCC / 0 xAA / 0 xAC | | Firebase RTDB
| ( Pi <-> PIC , 9600 8 N1 ) | | (/ pump_state )
v | v
+ - - - - - - - - - - - - - - - - - - - - - - - - - - - - - - - - - - -+ | + - - - - - - - - - - - - - - - - - - - - - - - - -+

| | LAYER 2 -- PIC16F877A | | | | | LAYER 3 -- ESP8266 | |
| | ADC scan -> Safety FSM -> Prio | | | | | Wi - Fi connect | |
| | Engine -> Motion / Pump - req | | | | | Subscribe / pump_state | |
| | | | | | Drive relay GPIO | |
| | ( Pump force - off -> Pi via UART ) | | | | | ( NO UART link to PIC ) | |
+ - - - - - - - -+ - - - - - - - - - - - - - - - - - - - - - - - - - - - - - - -+ - - - - - - - - - -+ - - - - - - - - - - - -+
v | v
+ - - - - - - - - - - - - - - - - - - - - - - - - - - - - - - - - - - - - - - - -+ | + - - - - - - - - - -+
| | LAYER 1 -- Physical | | | | RELAY -> |
| | Soil | LM35 | ACS712 | HC - SR04 | | | | | PUMP | |
| | Stepper | LCD | Keypad | LEDs | | | + - - - - - - - - - -+
+ - - - - - - - - - - - - - - - - - - - - - - - - - - - - - - - - - - - - - - - -+
3.5. Communication Protocol Contract
UART (PIC ↔ Pi), 9600 8N1:
Direction | Start Byte | Frame Format | Purpose
App → PIC (via Pi) | 0xCC | [0xCC][CMD_ID][P1][P2][CRC][0xDD]Gantry move, e-stop,
pump-request
AI → PIC (via Pi) | 0xBB | [0xBB][PROTO_ID][ZONE_X][0x00][P1][P2][CRC][0xEE]AI action protocols
PIC → Pi | 0xAA | [0xAA][S1][S2][S3][S4][STATUS][CRC][0x55]Telemetry batch
PIC → Pi | 0xAC | [0xAC][ACK/NACK][CMD_ECHO][0x55]Command | conrma-
tion

Pump-state path (Pi → Firebase → ESP):

/ pump_state : " ON " | " OFF "

The Pi writes to this path after consulting the PIC's safety status. The ESP reads this key on every refresh tick (∼500 ms) and sets its relay GPIO accordingly.

4. Safety-Critical Features Pseudocode

All four safety features implement the mandatory two-level output structure: a warning level (amber LED + buzzer pulse + LCD message + alert ag to Pi) followed by an action level (red LED + actuator cuto + system lockout). All features include hysteresis on recovery to prevent oscillation around thresholds.
When the PIC enters any lockout state:
1. The PIC disables the stepper enable line directly (RC2 = HIGH).
2. The PIC sends a STATUS byte with the lockout ag set; the Pi reads this and immediately writes /pump_state = "OFF" to Firebase, which propagates to the ESP within ∼500 ms.
4.1. Dry-Run Protection
Prevents pump damage by ensuring water-tank level is sucient before and during operation.
DEFINE WARN_LEVEL_CM | = 15 | # Warning when water surface > 15 cm below
sensor
DEFINE ACTION_LEVEL_CM = 8 | # Hard cutoff distance
DEFINE RECOVERY_CM | = 20 | # Tank must refill past this to clear lockout

FUNCTION check_dry_run () :
level = read_HCSR04 () | # ultrasonic distance to water
IF level > ACTION_LEVEL_CM AND level <= WARN_LEVEL_CM :

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

SET red_LED = ON
SET buzzer = CONTINUOUS
LCD_print (" OVERCURRENT ")
STATE = LOCKOUT_OC
ELSE IF STATE == LOCKOUT_OC AND | current | <= RECOVERY_CURRENT :
WAIT_for_manual_reset () # requires keypad '* ' confirm STATE = NORMAL
4.4. Overheat Protection
Monitors temperature near the driver and pump to prevent thermal damage.

DEFINE WARN_TEMP_C = 55
DEFINE ACTION_TEMP_C = 70
DEFINE RECOVERY_TEMP = 45

FUNCTION check_overheat () :
voltage = read_ADC ( CH1 ) * (5.0/1024)
temp_c = voltage * 100 | # LM35 : 10 mV/ degC

IF temp_c >= WARN_TEMP_C AND temp_c < ACTION_TEMP_C : SET amber_LED = ON
LCD_print (" TEMP HIGH ")
SET status_byte . temp_warn = 1
STATE = WARNING
ELSE IF temp_c >= ACTION_TEMP_C :
SET status_byte . lockout = LOCKOUT_TEMP DISABLE stepper ( RC2 = HIGH )
SET red_LED = ON
SET buzzer = CONTINUOUS
LCD_print (" OVERHEAT LOCK ")
STATE = LOCKOUT_TEMP
ELSE IF STATE == LOCKOUT_TEMP AND temp_c <= RECOVERY_TEMP : STATE = NORMAL
4.5. Command Priority Engine (Safety Arbitration)

FUNCTION execute_command ( cmd ) :
# Always run all safety checks before any actuation check_dry_run ()

check_overwater ()
check_overcurrent ()
check_overheat ()

IF any_state == LOCKOUT_ *:
SEND_NACK ( cmd , REASON = current_lockout_state )
# Pi receives via telemetry , writes / pump_state =" OFF" to Firebase , # ESP reads it and opens the relay

RETURN BLOCKED

IF cmd . source == AI :
IF app_cancel_within_grace_period (30 _seconds ) : SEND_NACK ( cmd , REASON = USER_CANCELLED ) RETURN CANCELLED

perform_action ( cmd )
SEND_ACK ( cmd )
5. PIC16F877A Pin Conguration

Pin(s) | Connected To | Interface | Direction
RA0/AN0 | Capacitive Soil Moisture | ADC Ch0 | Analog In
RA1/AN1 | LM35 Temperature | ADC Ch1 | Analog In
RA2/AN2 | ACS712 Current Sensor | ADC Ch2 | Analog In
RA3, RA4, RA5 | Keypad Columns 13 | Digital | Input (pull-up)
RB0 | HC-SR04 Trigger | Digital | Output
RB1 | HC-SR04 Echo | Timer1 Capture Input
RB2 | Piezo Buzzer (via 2N2222) | Digital | Output
RB3 | Limit Switch (homing) | Digital | Input (pull-up)
RB4RB7 | Keypad Rows | Digital | Output (scan)
RC0 | STEP_X (DRV8825) | Digital | Output
RC1 | DIR_X (DRV8825) | Digital | Output
RC2 | ENABLE_X (DRV8825) | Digital | Output (active LOW)
RC3RC5 | Reserved (was Y-axis) | | Available
RC6 | UART TX → Raspberry Pi RX | USART | Output
RC7 | UART RX ← Raspberry Pi TX | USART | Input
RD0 | (Reserved pump now via ESP) | Digital | Available
RD1 | Spare relay channel | Digital | Output (Active LOW)
RD2 | LCD RS | Digital | Output
RD3 | LCD Enable | Digital | Output
RD4RD7 | LCD Data (4-bit) | Digital | Output
RE0 | Keypad Column 4 | Digital | Input (pull-up)
RE1 | Amber LED (Warning) | Digital | Output
RE2 | Red LED (Fault) | Digital | Output
OSC1/OSC2 | 20 MHz Crystal + 2× 22 pF | Clock |
MCLR | Reset pull-up + push button | Digital | Input

Note

Conguration registers: ADCON1 = 0x04 (AN0AN2 analog, rest digital); USART 9600 8N1; TRISC = 0b10000000 (RC7 input, rest outputs).
Note on RD0: In the revised architecture, the pump is no longer wired directly to the PIC. The pump relay is driven by an ESP8266 GPIO. RD0 is therefore freed for future expansion (e.g., second pump zone or solenoid valve). The PIC inuences the pump indirectly: its safety status reaches the Pi, which writes Firebase, which the ESP reads.
6. Software Architecture
6.1. Embedded Layer (PIC16F877A MikroC Pro)

Main loop (100 ms cycle):

INIT :
configure_oscillator (20 MHz )
configure_ADC ( ADCON1 =0 x04 )
configure_USART (9600 , 8 , N , 1)
configure_timers ( T1 for HC - SR04 , T2 for stepper pulses ) init_LCD_4bit ()
homing_sequence ()

MAIN_LOOP :
scan_sensors_ADC () | // 3 channels + ultrasonic
evaluate_safety_FSM () | // 4 features in sequence
process_UART_RX_queue () | // arbitrate via Priority Engine
process_keypad ()
update_LCD ()
push_telemetry_if_due () // every 5 s, 0xAA frame to Pi WAIT_until_next_100ms_tick ()

Module structure:

main.c boot, scheduler
adc.c sensor scanning + scaling
safety.c four safety FSMs
motion.c homing_sequence(), move_to_plant() uart.c TX/RX ISR + frame parser
priority.c Command Priority Engine
lcd.c, keypad.c UI drivers
frame_defs.h shared with Pi-side parser
6.2. Pump-Relay Layer (ESP8266 Arduino Core / PlatformIO)

Single responsibility: mirror /pump_state from Firebase to a relay GPIO. The entire rmware is approximately 80 lines.

INIT :
WiFi . begin ( SSID , PASS )
Firebase . begin ( URL , AUTH )
pinMode ( RELAY_GPIO , OUTPUT )
digitalWrite ( RELAY_GPIO , HIGH ) // relay OFF (active - LOW board ) last_state = " OFF"

LOOP ( every 500 ms ) :
IF WiFi . status () != CONNECTED :
digitalWrite ( RELAY_GPIO , HIGH ) // fail - safe OFF reconnect ()
RETURN
state = Firebase . getString ("/ pump_state ")
IF state == "ON" AND last_state != "ON": digitalWrite ( RELAY_GPIO , LOW ) // engage pump last_state = "ON"
ELSE IF state == " OFF" AND last_state != "OFF ": digitalWrite ( RELAY_GPIO , HIGH ) // disengage pump last_state = " OFF"

Note
Fail-safe behavior: On Wi-Fi loss, the ESP defaults the relay to OFF. This is intentional a disconnected ESP cannot deliver water, eliminating any risk of stuck-on irrigation during network outages.

6.3. Host & AI Layer (Raspberry Pi 4 Python)

The Pi runs three concurrent processes managed by systemd:

Process 1 pic_bridge.py

Owns /dev/ttyAMA0 (UART to PIC) at 9600 baud.
Reads 0xAA telemetry frames and parses sensor values + safety status byte.
Pushes sensor readings to Firebase RTDB at /sensors/.
On lockout ag detected → immediately writes /pump_state = "OFF" to Firebase. Forwards incoming app commands (received via local socket) as 0xCC frames to PIC.

Process 2 ai_daemon.py

Loads mobilenetv2_int8.tflite.
Listens for trigger from app backend (scheduled scan or manual scan).
For each plant: sends 0xBB CMD_MOVE to PIC via local socket → waits ACK → captures image → infers → builds Action Protocol Packet.
Uploads detection images to Firebase Storage.

Process 3 app_backend.py (Flask / FastAPI)

Serves the Flutter web build on port 80.
Exposes REST and WebSocket endpoints for: pump control, gantry move, irrigation start/stop, schedule CRUD, AI scan trigger, alert subscription.
All pump-control endpoints write to /pump_state in Firebase only if the latest PIC status ag indicates no lockout.

Firebase RTDB Schema

/ sensors /
/ moisture | float (%)
/ temperature | float ( degC )
/ current | float ( A )
/ water_level | float ( cm )
/ timestamp | unix
/ status /
/ lockout | " NONE "|" DRY "|" WET "|" OC "|" TEMP "
/ position | int ( current plant index )
/ grace_active | bool
/ pump_state | " ON "|" OFF " | <- ESP reads this key
/ ai /
/ last_detection { plant , class , confidence , image_url , timestamp } / alerts /
/[ push_id ] | { type , value , timestamp }
/ commands /
/ move_to | int
/ irrigate | { plant : int , duration_ms : int }
/ e_stop | bool
7. Machine Learning Pipeline
7.1. Dataset
The training set combines three sources into a unied six-class taxonomy:

Class | Primary Source | Approx. Images | Augmented Total
Healthy | PlantVillage healthy subset | 10,500 | 21,000
Early Blight | PlantVillage (tomato, potato) | 8,400 | 16,800
Late Blight | PlantVillage (tomato, potato) | 9,200 | 18,400
Pest | IP102 subset (relabelled) | 7,800 | 15,600
Nutrient Deciency | PlantVillage (nitrogen-decient) | 5,500 | 11,000
Unknown / Background | Custom Pi Camera captures (campus) | ≈500 | 5,000

The custom Unknown class is critical: it captures empty pots, soil-only frames, and out-ofdistribution images, allowing the inference daemon to reject low-condence frames rather than forcing a misclassication.
Augmentation pipeline: random rotation (±30◦
), horizontal ip, brightness shift (±20%), random crop (90100%), Gaussian noise (σ = 0.01).
7.2. Training
Architecture: MobileNetV2 base (ImageNet pretrained), 100 layers frozen, global-averagepooling head, Dense(128, ReLU), Dropout(0.3), Dense(6, softmax).
Hyperparameters:

Optimizer: Adam, learning rate 10⁻⁴ with cosine decay
Batch size: 32
Epochs: 20 (early stopping patience = 5)
Loss: categorical cross-entropy with class weights
Split: 80% train / 10% validation / 10% test
Target metric: test accuracy ≥ 92%, per-class F1 ≥ 0.88
7.3. Quantization and Deployment
The oat32 model is converted to TFLite INT8 using representative-dataset calibration (200 images from validation). Post-quantization accuracy drop must remain under 2%. Final model size target: < 4 MB, enabling sub-200 ms inference on Pi 4.
Deployment steps:
1. Install tflite-runtime on Raspberry Pi OS.
2. Copy model + label map to /opt/irrigation/models/.
3. Register ai_daemon.py as a systemd service.
4. Validate end-to-end latency: capture → infer → packet TX < 1000 ms.
5. Push model, dataset card, and Jupyter notebook to HuggingFace, cited in README.md.
7.4. Action Protocol Mapping
Class | PROTO_ID | Action
Healthy | 0x01 | Log only, no actuation
Early Blight | 0x02 | Reduce irrigation duration by 30% for aected
| plant
Late Blight | 0x03 | Alert user, ag plant for manual inspection,
| skip irrigation
Pest | 0x04 | Targeted spray pulse (3 s) at plant location
Nutrient Deciency | 0x05 | Increase irrigation by 20%, notify user to add
| fertilizer
Unknown | 0x06 | Flag for human review, no action

8. Mechanical Design Summary

The mechanical subsystem is a 1-axis linear gantry (redesigned from a 2-axis concept, saving 49% on motion-system BOM). The carriage travels along a top-mounted GT2 belt drive over a 450 mm range, supported by an 8 mm hardened rod with two LM8UU bearings. The pump is xed at the base and connects to a nozzle on the carriage via 8 mm silicone tubing.
Six custom parts are 3D-printed in PLA+: drive-end bracket, idler-end bracket, carriage plate, two belt clamp plates, control box, and two rod end holders. Total print time ≈ 17 hours; carriage mass kept under 80 g to prevent belt skip.

Linear resolution:
40 mm pitch circumference
3200 microsteps/revolution = 0.0125 mm/step

A homing limit switch on the drive-end bracket provides absolute zero reference; plant positions are stored as a step-count lookup table in PIC EEPROM, congurable via the keypad or mobile app.

9. Integration, Testing, and Results
9.1. Five-Week Execution with Gate Checkpoints
Gate | Week | Pass Criterion
G0 Env Ready | End W1 | Toolchains operational, repo accessible to all 5 mem- bers
G1 Sensors + Safety | End W2 | All ADC channels within 5%, each safety feature res correctly
G2 Subsystems Standalone | End W3 | PIC controls motion + UART; ML accuracy > 92%; ESP mirrors /pump_state
G3 Full Comms Chain | End W4 | App → PIC < 3 s; AI → PIC actuation; safety lock- out overrides pump within 1 s
G4 Demo Ready | End W5 | 5-minute unattended run; report + video + repo complete
9.2. Stream Assignments
Stream A (M1+M2):
Hardware & safety ADC, sensors, LCD/keypad, 4 safety algorithms, motion control, UART protocol, command engine on PIC.

Stream B (M3):
ML & AI actuation dataset prep, MobileNetV2 training, TFLite quantization, Pi inference daemon, HuggingFace publication.

Stream C (M4):
IoT & app Firebase schema, ESP pump-bridge rmware, Pi app backend (Flask/-FastAPI), Flutter web frontend.

Stream D (M5):
3D design & mechanical Fusion 360 / OpenSCAD parts, gantry assembly, wiring harness, photos and demo video.

9.3. Performance Targets
Metric | Target | Verication Method
ADC accuracy | ±5% vs multimeter | Bench calibration
Safety response time | <100 | ms | warning,
<200 ms action

Logic analyzer on RE2

Safety → pump-o latency | <1 s end-to-end | Stopwatch (PIC lockout → relay
open)
Plant ML accuracy | ≥92% test | Confusion matrix on held-out
10%
Inference latency | <200 ms | Pi time.perf_counter()
App → actuator latency | <3 s | Stopwatch on round-trip
Carriage positioning | ±2 mm | Caliper at 5 plant points
5-min unattended demo | Zero crashes | Demo rehearsal log
9.4. Replicability

The repository (github.com/Ahmedshaban123r/smart-irrigation) is structured for full replicability:

smart - irrigation /
| - - README . md | # Setup steps for all 3 units
| - - mikroC - project / | # PIC firmware ( MikroC Pro )
| - - esp - firmware / | # PlatformIO project ( pump bridge only )
| - - pi - host /
| | | -- pic_bridge . py
| | | -- ai_daemon . py
| | | -- app_backend . py
| | | -- requirements . txt
| | `-- Dockerfile
| - - flutter - app / | # Flutter web build , served by Pi
| - - mechanical / | # OpenSCAD + STLs
| - - docs / | # Engineering documents
`-- notebook / | # . ipynb with training results
10. Conclusion

This project demonstrates the successful integration of four engineering disciplines embedded systems, IoT communications, machine learning, and mechanical design into a single, cohesive cyber-physical platform.
The architectural choice that most distinguishes this implementation is the deliberate minimization of the ESP8266's scope: rather than acting as a full bidirectional bridge, it is reduced to a single-key relay subscriber whose only job is to mirror /pump_state from Firebase to the pump's relay GPIO. This concentrates the system's intelligence on the Raspberry Pi (which already has Wi-Fi, a full Linux stack, and the AI pipeline) and reserves the most safety-critical actuator path for a dedicated, predictable MCU with no other duties. The result is a system where safety-critical decisions originate on the PIC, propagate to the Pi via UART, are written to Firebase, and reach the pump relay via the ESP with the Pi able to assert pump-o independently and immediately whenever a lockout ag is detected.
The four safety-critical features dry-run, overwatering, overcurrent, and overheat each implement the required two-level warning-then-action structure with deterministic recovery hysteresis. The 1-axis redesign yielded a 49% saving on motion-system BOM cost while preserving full architectural compatibility for future 2-axis extension. The on-device TFLite INT8 inference pipeline eliminates cloud dependency for vision decisions, and the 30-second user-override grace period ensures autonomous AI actions remain accountable to the human operator.

The system fullls all ve coursework specications:

Complete user-interfacing input/output (LCD, keypad, Flutter app hosted on the Pi).

Multi-sensor and multi-actuator fusion with Pi and µC integration (no Arduino used).

Four independent safety-critical features with two-level outputs.

A machine-learning feature with HuggingFace publication.

A clean, documented, replicable codebase across all three computational units.
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

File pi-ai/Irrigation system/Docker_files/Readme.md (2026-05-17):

# 🌱 Smart Precision Irrigation System

AI-powered plant disease detection using TFLite + Raspberry Pi.

---

## 📁 Project Structure

```
Irrigation system/
├── Dockerfile
├── requirements.txt
├── main.py
├── pi_daemon.py
├── model.tflite
├── class_names.json
├── Test_Images/          ← put your leaf images here
│   └── leaf.jpg
└── results/
    └── run_logs.json
```

---

## 🚀 How to Run

### 1. Install Docker Desktop
Download from: https://www.docker.com/products/docker-desktop

### 2. Build the image (once)
```
docker build -t irrigation-system .
```

### 3. Run inference with your image
```
docker run -v "%cd%\results:/app/results" -v "%cd%\Test_Images\YOUR_IMAGE.jpg:/app/test.jpg" irrigation-system

ex:
docker run -v "C:\Users\HP\Desktop\Irrigation system\results:/app/results" -v "C:\Users\HP\Desktop\Irrigation system\Test_Images\leaf.jpg:/app/test.jpg" irrigation-system

```

> Replace `YOUR_IMAGE.jpg` with your leaf image filename inside `Test_Images/`.
> Results will be saved to `results/run_logs.json` automatically.

---

## 📊 Output

Each run logs 50 inferences with:
- Predicted class (Healthy / Early_Blight / Late_Blight / Pest / Nutrient_Deficiency)
- Confidence score
- UART protocol packet
- Inference time (ms)

### Example output:
```
[01/50] Early_Blight   conf=99.61%  proto=0x02  infer=60ms
...
✅ Success Rate   : 100.00% (50/50)
⚡ Avg Inference  : 59.2ms
```

---

## 🔧 Classes & Protocols

| Class | Protocol | Action |
|---|---|---|
| Healthy | 0x01 | Continue normal |
| Early Blight | 0x02 | Reduce irrigation |
| Late Blight | 0x03 | Emergency dry |
| Pest | 0x04 | Targeted spray |
| Nutrient Deficiency | 0x05 | Increase irrigation |

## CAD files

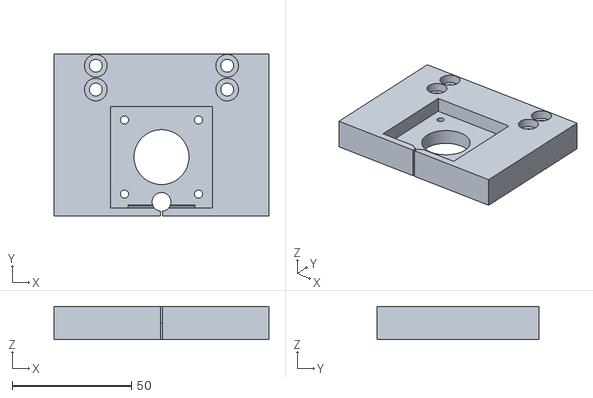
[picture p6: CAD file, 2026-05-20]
mechanical/stl/Part1_Drive_End_Bracket_v7.stl
90.0 x 68.0 x 14.0

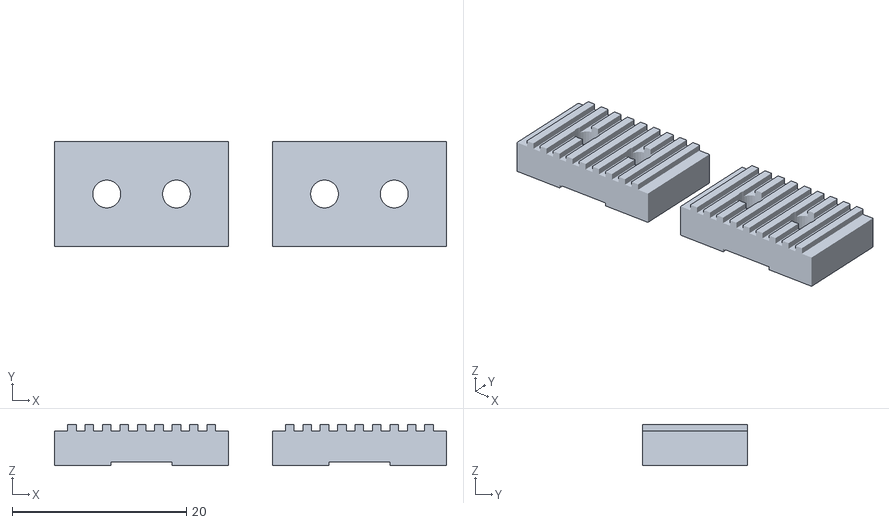
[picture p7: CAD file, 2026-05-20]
mechanical/stl/Part4_Belt_Clamp_x2.stl
45.0 x 12.0 x 4.75

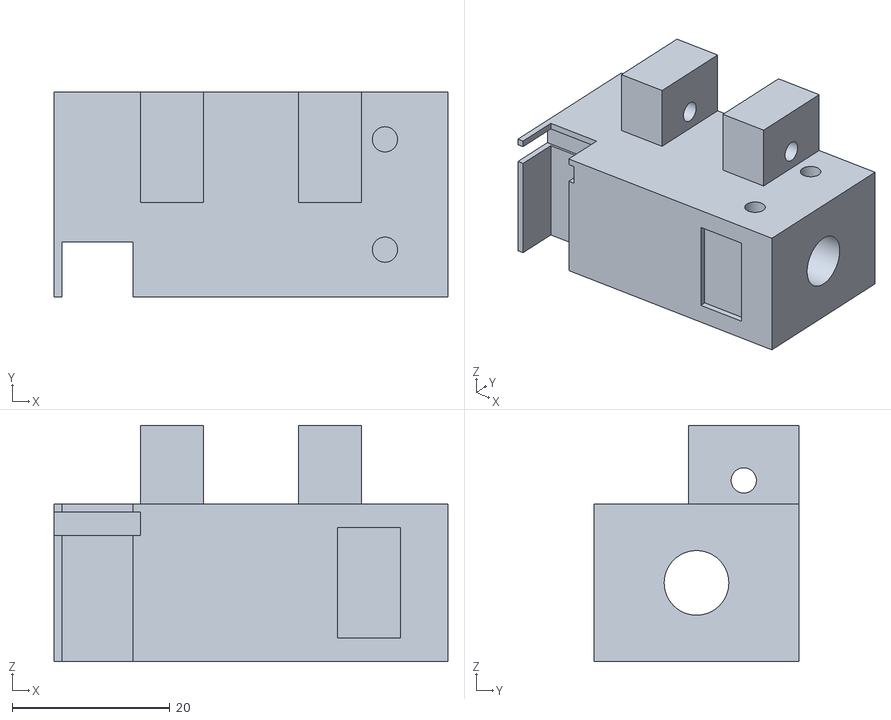
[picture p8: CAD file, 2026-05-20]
mechanical/stl/Part3_Carriage_Plate_v4_1.stl
50.0 x 26.0 x 30.0

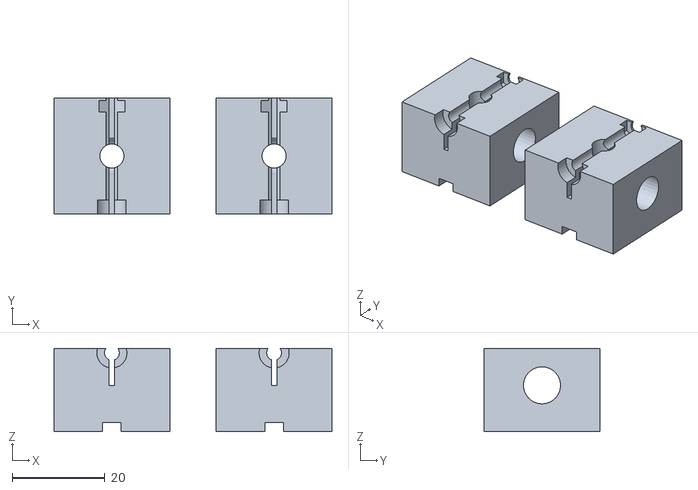
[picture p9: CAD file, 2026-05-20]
mechanical/stl/Part6_Rod_End_Holder_x2.stl
60.0 x 25.0 x 18.0

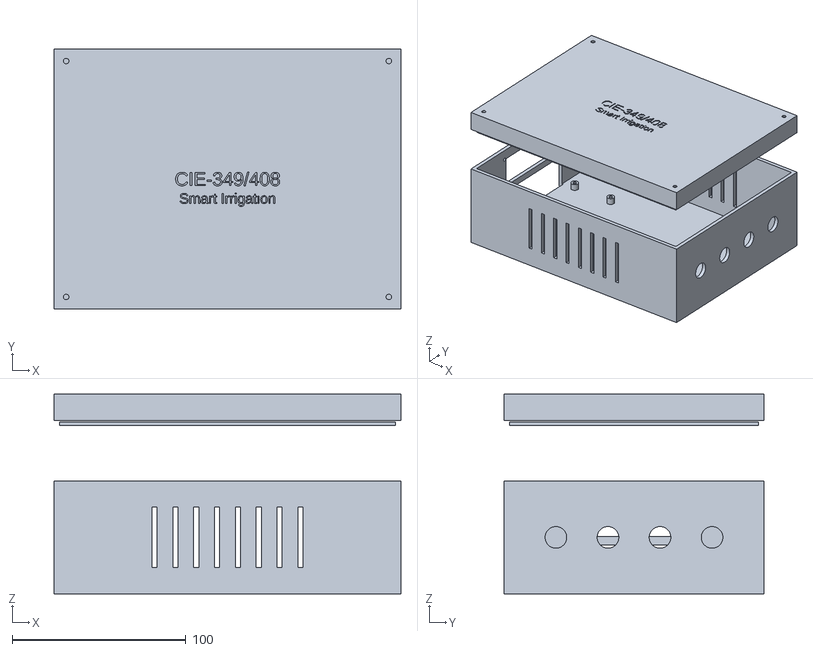
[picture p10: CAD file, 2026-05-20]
mechanical/stl/Part5_Control_Box.stl
200.0 x 150.0 x 115.0

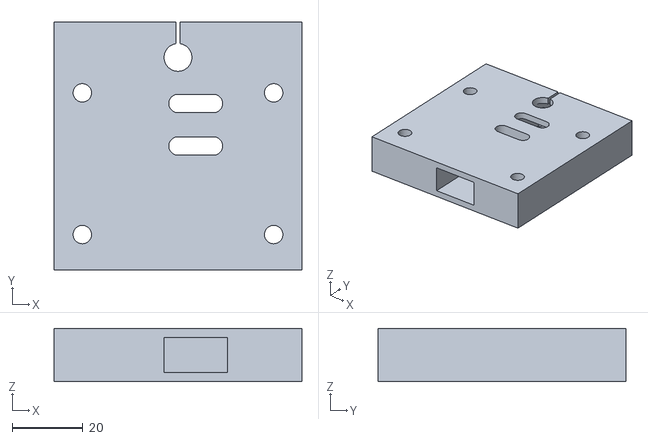
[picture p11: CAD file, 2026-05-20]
mechanical/stl/Part2_Idler_End_Bracket.stl
70.0 x 70.0 x 15.0

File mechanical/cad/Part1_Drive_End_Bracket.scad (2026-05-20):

// ============================================================
// PART 1 — Drive-End Bracket
// AI-Based Smart Precision Irrigation System (1-Axis)
// ============================================================
// Dimensions: 80 x 70 x 20 mm
// Material: PLA+, 0.20mm layer, 40% infill, 4 perimeters
// Print time: ~3.5 hours
// Print orientation: Flat on back face (NEMA17 face UP)
// ============================================================

/* [Bracket Parameters] */
bracket_w = 80;       // X width
bracket_d = 70;       // Y depth
bracket_h = 20;       // Z thickness

/* [NEMA17 Parameters] */
nema_hole_spacing = 31;    // Bolt circle (center-to-center)
nema_center_bore  = 23;    // Motor collar clearance
nema_screw_dia    = 3.2;   // M3 clearance (0.2mm over)
nema_center_x     = 40;    // Motor center X
nema_center_y     = 35;    // Motor center Y

/* [Smooth Rod] */
rod_bore_dia      = 7.85;  // 8mm rod, 0.15mm interference for press-fit
rod_center_x      = 40;
rod_center_y      = 60;
rod_slit_width    = 1.0;   // Clamping slit
pinch_bolt_dia    = 3.2;   // M3 pinch bolt

/* [Extrusion Mounting] */
ext_bolt_dia      = 5.2;   // M5 clearance
ext_cbore_dia     = 8.5;   // M5 counterbore
ext_cbore_depth   = 4;     // Counterbore depth
ext_hole_x        = [8, 72]; // Bolt X positions
ext_hole_y        = [10, 50]; // Bolt Y positions

/* [Limit Switch Tab] */
sw_tab_w          = 15;
sw_tab_d          = 18;
sw_tab_h          = 20;
sw_hole_dia       = 2.2;   // M2 clearance
sw_hole_spacing   = 9.5;   // Standard micro switch

/* [Belt Path] */
belt_slot_w       = 8;
belt_slot_h       = 10;

$fn = 40;

module drive_end_bracket() {
    difference() {
        union() {
            // Main bracket body
            cube([bracket_w, bracket_d, bracket_h]);

            // Limit switch mounting tab (extends from side)
            translate([bracket_w - 5, (bracket_d - sw_tab_d) / 2 - 10, 0])
            cube([sw_tab_w + 5, sw_tab_d, sw_tab_h]);
        }

        // === NEMA17 CENTER BORE ===
        translate([nema_center_x, nema_center_y, -1])
        cylinder(d=nema_center_bore, h=bracket_h + 2);

        // === NEMA17 MOUNTING HOLES (31mm bolt circle) ===
        for (dx = [-1, 1], dy = [-1, 1]) {
            translate([
                nema_center_x + dx * nema_hole_spacing / 2,
                nema_center_y + dy * nema_hole_spacing / 2,
                -1
            ])
            cylinder(d=nema_screw_dia, h=bracket_h + 2);

            // Counterbore on bottom for bolt heads
            translate([
                nema_center_x + dx * nema_hole_spacing / 2,
                nema_center_y + dy * nema_hole_spacing / 2,
                -1
            ])
            cylinder(d=6.5, h=ext_cbore_depth + 1);
        }

        // === SMOOTH ROD BORE (press-fit) ===
        translate([rod_center_x, rod_center_y, -1])
        cylinder(d=rod_bore_dia, h=bracket_h + 2);

        // === ROD CLAMPING SLIT ===
        translate([rod_center_x - rod_slit_width/2, rod_center_y, -1])
        cube([rod_slit_width, bracket_d - rod_center_y + 1, bracket_h + 2]);

        // === ROD PINCH BOLT (M3, horizontal) ===
        translate([rod_center_x - 15, rod_center_y + 5, bracket_h / 2])
        rotate([0, 90, 0])
        cylinder(d=pinch_bolt_dia, h=30);

        // === EXTRUSION MOUNT HOLES (M5 counterbored) ===
        for (ex = ext_hole_x, ey = ext_hole_y) {
            // Through hole
            translate([ex, ey, -1])
            cylinder(d=ext_bolt_dia, h=bracket_h + 2);
            // Counterbore (bottom side)
            translate([ex, ey, -1])
            cylinder(d=ext_cbore_dia, h=ext_cbore_depth + 1);
        }

        // === BELT PATH CLEARANCE SLOTS ===
        // Slot for belt to pass from motor pulley to carriage
        translate([nema_center_x - belt_slot_w/2, -1, bracket_h / 2 - belt_slot_h / 2])
        cube([belt_slot_w, nema_center_y - nema_center_bore/2, belt_slot_h]);

        translate([nema_center_x - belt_slot_w/2, nema_center_y + nema_center_bore/2, bracket_h / 2 - belt_slot_h / 2])
        cube([belt_slot_w, bracket_d - nema_center_y, belt_slot_h]);

        // === LIMIT SWITCH HOLES (M2) ===
        sw_base_x = bracket_w + sw_tab_w / 2;
        sw_base_y = (bracket_d - sw_tab_d) / 2 - 10;
        translate([sw_base_x, sw_base_y + sw_tab_d/2 - sw_hole_spacing/2, -1])
        cylinder(d=sw_hole_dia, h=sw_tab_h + 2);
        translate([sw_base_x, sw_base_y + sw_tab_d/2 + sw_hole_spacing/2, -1])
        cylinder(d=sw_hole_dia, h=sw_tab_h + 2);

        // === WEIGHT REDUCTION POCKET (underside) ===
        translate([20, 15, -1])
        hull() {
            cylinder(d=8, h=6);
            translate([40, 0, 0]) cylinder(d=8, h=6);
            translate([40, 15, 0]) cylinder(d=8, h=6);
            translate([0, 15, 0]) cylinder(d=8, h=6);
        }
    }
}

// Render
drive_end_bracket();

// === PRINT NOTES ===
// Orientation: Print with NEMA17 face pointing UP (back face on bed)
// Layer lines perpendicular to motor pulling force
// Supports: None needed
// First layer: 0.25mm for adhesion
// Brim: 5mm recommended for flat adhesion

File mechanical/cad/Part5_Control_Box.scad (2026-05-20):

// ============================================================
// PART 5 — Control Box (Base + Lid)
// AI-Based Smart Precision Irrigation System (1-Axis)
// ============================================================
// External: 200 x 150 x 80 mm
// Wall: 3mm, Material: PLA+, 0.20mm layer, 25% infill, 3 perimeters
// Print time: ~8 hours (base ~5h, lid ~3h)
// Print: Base open-face UP, Lid flat face DOWN
// ============================================================

/* [Box Dimensions] */
box_w    = 200;      // X (front-to-back)
box_d    = 150;      // Y (side-to-side)
box_h    = 80;       // Z total height
wall     = 3;        // Wall thickness
lid_h    = 15;       // Lid portion height (splits from box_h)

/* [LCD 1602 Window] */
lcd_w    = 71;       // Display visible area width
lcd_h    = 24;       // Display visible area height
lcd_off_top = 8;     // Offset from top of front face
lcd_mount_w = 80;    // PCB width (for screw tabs)
lcd_mount_h = 36;    // PCB height
lcd_screw   = 2.8;   // M2.5 self-tap holes

/* [Keypad 4x4 Window] */
kp_w     = 69;
kp_h     = 77;
kp_gap   = 5;        // Gap between LCD and keypad

/* [LED Holes] */
led_dia  = 5.1;      // 5mm LED + clearance
led_num  = 3;
led_spacing = 15;

/* [Cable Glands (PG7)] */
gland_dia = 12.5;    // PG7 hole diameter
gland_num = 4;
gland_spacing = 30;

/* [Ventilation] */
vent_slots    = 8;
vent_w        = 3;    // Slot width
vent_h        = 35;   // Slot height
vent_spacing  = 12;

/* [Internal Mounting] */
standoff_h   = 5;     // PCB standoff height
standoff_dia = 6;     // Standoff outer diameter
standoff_hole = 2.8;  // M2.5 self-tap

/* [Lid Fastening] */
lid_screw_dia = 3.2;  // M3 clearance
lid_boss_dia  = 8;    // Boss around screw hole
insert_dia    = 4.2;  // M3 brass heat-set insert

/* [Gasket Groove] */
gasket_w     = 1.5;
gasket_d     = 1.0;

$fn = 30;

// ============================================================
// BASE (bottom portion, contains all electronics)
// ============================================================
module control_box_base() {
    base_h = box_h - lid_h;

    difference() {
        union() {
            // Outer shell
            cube([box_w, box_d, base_h]);

            // Lid screw bosses (4 corners, extending up)
            for (bx = [wall + lid_boss_dia/2, box_w - wall - lid_boss_dia/2],
                 by = [wall + lid_boss_dia/2, box_d - wall - lid_boss_dia/2])
                translate([bx, by, 0])
                cylinder(d=lid_boss_dia, h=base_h);
        }

        // Hollow interior
        translate([wall, wall, wall])
        cube([box_w - 2*wall, box_d - 2*wall, base_h + 1]);

        // === FRONT FACE CUTOUTS (X = 0 face) ===

        // LCD window
        lcd_y = (box_d - lcd_w) / 2;
        lcd_z = base_h - lcd_off_top - lcd_h;
        translate([-1, lcd_y, lcd_z])
        cube([wall + 2, lcd_w, lcd_h]);

        // LCD mounting screw holes (4 corners of PCB)
        lcd_mount_y = (box_d - lcd_mount_w) / 2;
        lcd_mount_z = base_h - lcd_off_top - lcd_mount_h + 3;
        for (sy = [lcd_mount_y + 3, lcd_mount_y + lcd_mount_w - 3],
             sz = [lcd_mount_z + 3, lcd_mount_z + lcd_mount_h - 3])
            translate([-1, sy, sz])
            rotate([0, 90, 0])
            cylinder(d=lcd_screw, h=wall + 5);

        // Keypad window
        kp_y = (box_d - kp_w) / 2;
        kp_z = lcd_z - kp_gap - kp_h;
        translate([-1, kp_y, kp_z])
        cube([wall + 2, kp_w, kp_h]);

        // LED holes (above LCD)
        led_base_y = box_d/2 - (led_num - 1) * led_spacing / 2;
        for (li = [0 : led_num - 1])
            translate([-1, led_base_y + li * led_spacing, base_h - 4])
            rotate([0, 90, 0])
            cylinder(d=led_dia, h=wall + 2);

        // === REAR FACE CUTOUTS (X = box_w face) ===

        // Cable glands (PG7)
        gland_base_y = box_d/2 - (gland_num - 1) * gland_spacing / 2;
        for (gi = [0 : gland_num - 1])
            translate([box_w - wall - 1, gland_base_y + gi * gland_spacing, base_h / 2])
            rotate([0, 90, 0])
            cylinder(d=gland_dia, h=wall + 2);

        // === SIDE VENTILATION SLOTS (Y = 0 face) ===
        vent_start_x = (box_w - (vent_slots - 1) * vent_spacing) / 2;
        for (vi = [0 : vent_slots - 1])
            translate([vent_start_x + vi * vent_spacing - vent_w/2, -1, (base_h - vent_h) / 2])
            cube([vent_w, wall + 2, vent_h]);

        // Same on opposite side (Y = box_d)
        for (vi = [0 : vent_slots - 1])
            translate([vent_start_x + vi * vent_spacing - vent_w/2, box_d - wall - 1, (base_h - vent_h) / 2])
            cube([vent_w, wall + 2, vent_h]);

        // === LID SCREW HOLES (M3 heat-set inserts) ===
        for (bx = [wall + lid_boss_dia/2, box_w - wall - lid_boss_dia/2],
             by = [wall + lid_boss_dia/2, box_d - wall - lid_boss_dia/2])
            translate([bx, by, base_h - 12])
            cylinder(d=insert_dia, h=13);

        // === GASKET GROOVE (top rim) ===
        translate([wall + 2, wall + 2, base_h - gasket_d])
        difference() {
            cube([box_w - 2*wall - 4, box_d - 2*wall - 4, gasket_d + 1]);
            translate([gasket_w, gasket_w, -1])
            cube([box_w - 2*wall - 4 - 2*gasket_w, box_d - 2*wall - 4 - 2*gasket_w, gasket_d + 3]);
        }
    }

    // === INTERNAL STANDOFFS (for breadboard/PCB) ===
    // 4 standoffs for main breadboard
    color([0.5, 0.5, 0.45])
    for (sx = [15, 175], sy = [25, 70])
        translate([sx, sy, wall])
        difference() {
            cylinder(d=standoff_dia, h=standoff_h);
            translate([0, 0, -1])
            cylinder(d=standoff_hole, h=standoff_h + 2);
        }

    // 2 standoffs for ESP8266 NodeMCU (right wall)
    color([0.5, 0.5, 0.45])
    for (sy = [85, 130])
        translate([box_w - wall - 15, sy, wall])
        difference() {
            cylinder(d=standoff_dia, h=standoff_h);
            translate([0, 0, -1])
            cylinder(d=standoff_hole, h=standoff_h + 2);
        }

    // 2 standoffs for relay module (rear left)
    color([0.5, 0.5, 0.45])
    for (sx = [15, 50])
        translate([sx, box_d - 40, wall])
        difference() {
            cylinder(d=standoff_dia, h=standoff_h);
            translate([0, 0, -1])
            cylinder(d=standoff_hole, h=standoff_h + 2);
        }
}

// ============================================================
// LID (top portion)
// ============================================================
module control_box_lid() {
    difference() {
        union() {
            // Lid body
            cube([box_w, box_d, lid_h]);

            // Inner lip (seats into base opening)
            translate([wall + 0.3, wall + 0.3, -3])
            cube([box_w - 2*wall - 0.6, box_d - 2*wall - 0.6, 3]);
        }

        // Hollow (thin shell)
        translate([wall, wall, -1])
        cube([box_w - 2*wall, box_d - 2*wall, lid_h - wall + 1]);

        // Screw holes (M3 clearance, countersunk)
        for (bx = [wall + lid_boss_dia/2, box_w - wall - lid_boss_dia/2],
             by = [wall + lid_boss_dia/2, box_d - wall - lid_boss_dia/2]) {
            translate([bx, by, -5])
            cylinder(d=lid_screw_dia, h=lid_h + 10);
            // Countersink
            translate([bx, by, lid_h - wall - 1.5])
            cylinder(d1=lid_screw_dia, d2=7, h=3);
        }

        // Label engraving (top surface)
        translate([box_w/2, box_d/2, lid_h - 0.5])
        linear_extrude(0.6)
        text("CIE-349/408", size=8, halign="center", valign="center");

        translate([box_w/2, box_d/2 - 12, lid_h - 0.5])
        linear_extrude(0.6)
        text("Smart Irrigation", size=6, halign="center", valign="center");
    }
}

// ============================================================
// RENDER — choose what to display
// ============================================================

/* [Display] */
show_base = true;
show_lid  = true;
exploded  = true;   // Separate lid from base

if (show_base)
    control_box_base();

if (show_lid)
    translate([0, 0, exploded ? box_h + 20 : box_h - lid_h])
    control_box_lid();

// === PRINT NOTES ===
// BASE: Print open-face UP (bottom of box on bed)
//   - No supports needed
//   - Cable gland holes and vent slots are horizontal = clean
//   - Gasket groove prints cleanly at top layer
//
// LID: Print FLAT (outer face DOWN on bed)
//   - Inner lip prints upward
//   - Text engraving on top face
//   - No supports needed
//
// Post-processing:
//   - Install M3 brass heat-set inserts in base corner bosses
//     (use soldering iron at 220°C, press straight in)
//   - Test-fit LCD and keypad before final assembly
//   - Apply silicone gasket cord (1.5mm diameter) in groove
//   - Route cables through PG7 glands with strain relief

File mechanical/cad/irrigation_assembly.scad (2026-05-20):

// ============================================================
// AI-Based Smart Precision Irrigation System
// 1-Axis Linear Redesign — Full Assembly Visualization
// CIE-349/408 Embedded Systems — Spring 2026
// ============================================================
// Units: millimeters
// Open in OpenSCAD → Press F5 (Preview) or F6 (Render)
// Use the parameter panel (Window > Customizer) to toggle zones
// ============================================================

/* [Display Controls] */
show_frame       = true;   // Zone B: 2020 extrusions + rod
show_control_box = true;   // Zone A: electronics enclosure
show_carriage    = true;   // Zone C: moving platform
show_motor       = true;   // NEMA17 + pulley
show_idler       = true;   // Idler pulley assembly
show_belt        = true;   // GT2 belt path
show_pump        = true;   // Submersible pump + tube
show_plants      = true;   // Plant pots on ground
show_pi          = true;   // Raspberry Pi 4
show_camera      = true;   // Pi Camera v2 on carriage
show_limit_sw    = true;   // Homing limit switch
show_brackets    = true;   // Drive-end + idler-end brackets
show_rod_holders = true;   // Smooth rod end holders
show_labels      = false;  // Text labels (slow render)

/* [Carriage Position] */
// Plant index 0-4 or manual step position
carriage_plant_index = 2;  // [0:4]

/* [System Parameters] */
num_plants       = 5;
plant_spacing    = 80;     // mm between plants
first_plant_off  = 50;     // mm from home to first plant
rail_length      = 500;    // mm (2020 extrusion length)
rail_spacing     = 60;     // mm center-to-center
rod_diameter     = 8;      // mm smooth rod
frame_height     = 250;    // mm above ground (leg height)

// ============================================================
// DERIVED PARAMETERS
// ============================================================
carriage_x = first_plant_off + carriage_plant_index * plant_spacing;
belt_y_offset = rail_spacing / 2;
rod_y = 0; // centered between rails

// ============================================================
// COLOR PALETTE
// ============================================================
col_aluminum  = [0.75, 0.75, 0.78, 1.0];
col_black     = [0.15, 0.15, 0.15, 1.0];
col_pla_gray  = [0.55, 0.55, 0.50, 1.0];
col_pla_blue  = [0.30, 0.50, 0.75, 1.0];
col_green_pcb = [0.10, 0.45, 0.15, 1.0];
col_red       = [0.85, 0.20, 0.15, 1.0];
col_orange    = [0.90, 0.55, 0.10, 1.0];
col_belt      = [0.20, 0.20, 0.22, 1.0];
col_steel     = [0.60, 0.60, 0.62, 1.0];
col_copper    = [0.72, 0.45, 0.20, 1.0];
col_tube      = [0.70, 0.85, 0.90, 0.5];
col_soil      = [0.40, 0.28, 0.15, 1.0];
col_plant     = [0.20, 0.60, 0.15, 1.0];
col_pot       = [0.65, 0.35, 0.15, 1.0];
col_camera    = [0.25, 0.25, 0.28, 1.0];
col_pi        = [0.10, 0.50, 0.15, 1.0];
col_yellow    = [0.95, 0.85, 0.20, 1.0];
col_white     = [0.92, 0.92, 0.90, 1.0];

// ============================================================
// PRIMITIVE MODULES
// ============================================================

// 2020 V-Slot Aluminum Extrusion (simplified cross-section)
module extrusion_2020(length) {
    color(col_aluminum)
    difference() {
        cube([20, 20, length], center=false);
        // V-slot grooves (simplified)
        for (side = [0:3]) {
            rotate([0, 0, side * 90])
            translate([10, -0.5, -1])
            rotate([0, 0, 0])
            translate([-3, 0, 0])
            cube([6, 4, length + 2]);
        }
        // Center bore
        translate([10, 10, -1])
        cylinder(d=4.2, h=length+2, $fn=20);
    }
}

// Simplified 2020 extrusion (faster render)
module extrusion_2020_simple(length) {
    color(col_aluminum)
    translate([0, 0, 0])
    cube([20, 20, length]);
}

// NEMA17 Stepper Motor (42x42x40mm)
module nema17() {
    // Body
    color(col_black)
    difference() {
        translate([-21, -21, 0])
        cube([42, 42, 40]);
        // Corner chamfers
        for (cx = [-21, 21], cy = [-21, 21])
            translate([cx, cy, -1])
            rotate([0, 0, 45])
            cube([8, 8, 42], center=true);
    }
    // Front face plate
    color(col_steel)
    translate([0, 0, 40])
    cylinder(d=38.1, h=2, $fn=40);
    // Collar boss
    color(col_steel)
    translate([0, 0, 42])
    cylinder(d=22, h=2, $fn=30);
    // Shaft (5mm diameter, extends 24mm)
    color(col_steel)
    translate([0, 0, 42])
    cylinder(d=5, h=24, $fn=20);
    // Mounting holes (visual indicators)
    color(col_black)
    for (mx = [-15.5, 15.5], my = [-15.5, 15.5])
        translate([mx, my, 40])
        cylinder(d=3, h=3, $fn=12);
}

// GT2 20-tooth Pulley
module gt2_pulley() {
    color(col_aluminum) {
        // Toothed section
        cylinder(d=12.22, h=7, $fn=30);
        // Top flange
        translate([0, 0, 7])
        cylinder(d=16, h=1, $fn=30);
        // Bottom flange
        translate([0, 0, -1])
        cylinder(d=16, h=1, $fn=30);
    }
}

// GT2 Idler Pulley (toothless)
module gt2_idler() {
    color(col_aluminum) {
        difference() {
            union() {
                cylinder(d=12, h=7, $fn=30);
                translate([0, 0, 7])
                cylinder(d=16, h=1, $fn=30);
                translate([0, 0, -1])
                cylinder(d=16, h=1, $fn=30);
            }
            translate([0, 0, -2])
            cylinder(d=5, h=12, $fn=20);
        }
    }
}

// Smooth Rod
module smooth_rod(length, dia=8) {
    color(col_steel)
    rotate([0, 0, 0])
    cylinder(d=dia, h=length, $fn=30);
}

// LM8UU Linear Bearing
module lm8uu() {
    color(col_steel)
    difference() {
        cylinder(d=15, h=24, $fn=30);
        translate([0, 0, -1])
        cylinder(d=8.1, h=26, $fn=30);
    }
}

// Limit Switch (micro, SPDT lever type)
module limit_switch() {
    // Body
    color(col_black)
    cube([12.8, 5.8, 6.5]);
    // Lever arm
    color(col_steel)
    translate([12.8, 2.9, 5.5])
    rotate([0, 0, 0]) {
        cube([14, 0.5, 1]);
        // Roller
        translate([14, 0, 0.5])
        rotate([90, 0, 0])
        cylinder(d=3, h=0.5, center=true, $fn=16);
    }
    // Pins
    color(col_copper)
    for (px = [2, 6.4, 10.8])
        translate([px, 2.9, -3])
        cylinder(d=0.8, h=3, $fn=8);
}

// Pi Camera v2 Module
module pi_camera_v2() {
    // PCB
    color(col_green_pcb)
    cube([25, 24, 1]);
    // Sensor module
    color(col_black)
    translate([4, 5, 1])
    cube([8, 8, 3]);
    // Lens
    color(col_camera)
    translate([8, 9, 4])
    cylinder(d=6, h=2, $fn=20);
    // FFC connector
    color(col_white)
    translate([3, 20, -1])
    cube([19, 3, 1]);
}

// Raspberry Pi 4 (simplified)
module raspberry_pi_4() {
    // PCB
    color(col_pi)
    difference() {
        cube([85, 56, 1.6]);
        // Mounting holes (58x49mm pattern)
        for (hx = [3.5, 61.5], hy = [3.5, 52.5])
            translate([hx, hy, -1])
            cylinder(d=2.7, h=4, $fn=12);
    }
    // USB-C power
    color(col_steel)
    translate([7, -2, 1.6])
    cube([9, 4, 3.5]);
    // Micro HDMI x2
    color(col_steel)
    translate([22, -2, 1.6])
    cube([7, 4, 3]);
    translate([35, -2, 1.6])
    cube([7, 4, 3]);
    // USB-A x2 (stacked)
    color(col_steel)
    translate([69, -2, 1.6])
    cube([14, 18, 16]);
    // Ethernet
    color(col_steel)
    translate([69, 22, 1.6])
    cube([16, 16, 14]);
    // GPIO header
    color(col_black)
    translate([6, 29, 1.6])
    cube([51, 5, 8.5]);
    // CSI camera connector
    color(col_white)
    translate([38, 10, 1.6])
    cube([22, 3, 5]);
    // SoC heatspreader
    color(col_steel)
    translate([25, 22, 1.6])
    cube([14, 14, 2.5]);
}

// LCD 1602 Module
module lcd_1602() {
    // PCB
    color(col_green_pcb)
    cube([80, 36, 1.6]);
    // Display area
    color(col_pla_blue)
    translate([4.5, 6, 1.6])
    cube([71, 24, 3]);
}

// 4x4 Matrix Keypad
module keypad_4x4() {
    color(col_white)
    cube([69, 77, 1]);
    // Keys
    color(col_pla_gray)
    for (kx = [0:3], ky = [0:3])
        translate([8 + kx*15, 6 + ky*17, 1])
        cube([10, 10, 1.5]);
}
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

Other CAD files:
mechanical/cad/Part2_Idler_End_Bracket.scad
mechanical/cad/Part3_Carriage_Plate.scad
mechanical/cad/Part4_Belt_Clamp_x2.scad
mechanical/cad/Part6_Rod_End_Holder_x2.scad

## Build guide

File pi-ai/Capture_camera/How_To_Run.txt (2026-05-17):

chmod +x ~/irrigation/capture_and_infer.sh
./capture_and_infer.sh

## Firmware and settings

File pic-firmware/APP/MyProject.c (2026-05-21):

/*
 * MyProject.c
 * Smart Irrigation Controller — PIC16F877A @ 8 MHz
 * Compiler: MPLAB XC8 v2.36
 *
 * Hardware: single-channel relay on RD0 (pump only). Motor relay removed.
 *
 * FILE STRUCTURE
 *   Section 1 — Production main  (#if 0 … #endif)
 *               Full system: 2 plants 10 cm apart, 5-min cycle, Pi comms,
 *               all sensors, safety, auto/manual modes.
 *   Section 2 — Debug main  (active)
 *               No Pi, no timer. Motor oscillates: 5 cm fwd every 10 s,
 *               reverses after 10 cm. Shaft freed between moves.
 *
 * To activate production: change #if 0 → #if 1 and #if 1 → #if 0 below.
 */

#include "../config.h"
#include "../MCAL/MCU_Registers.h"

#pragma config FOSC = HS
#pragma config WDTE = OFF
#pragma config PWRTE = ON
#pragma config BOREN = ON
#pragma config LVP = OFF
#pragma config CPD = OFF
#pragma config WRT = OFF
#pragma config CP = OFF

#include "../HAL/LCD/LCD_interface.h"
#include "../SERVICES/STD_TYPES.h"
#include "../SERVICES/BIT_MATH.h"

/*
 * portd_shadow — RD0 = pump relay (active LOW, pump OFF = 1).
 * Starting at 0x01 keeps E/RS/D4-D7 LOW so LCD_Init gets a clean start.
 */
volatile u8 portd_shadow = 0x00u;
u8 last_temp_c = 25u;
volatile u8 g_tick_100ms = 0u;
u8 g_frame[4] = {0u};
u8 g_frame_idx = 0u;
u8 g_frame_ready = 0u;

/* ═══════════════════════════════════════════════════════════════════════════
   SECTION 1 — PRODUCTION MAIN  (flip to #if 1 to activate)
   2 plants, 10 cm apart. 5-min auto cycle. Full sensors + Pi comms.
   ═══════════════════════════════════════════════════════════════════════════ */
#if 0

#include "Safety/Safety_interface.h"
#include "Comms/Comms_interface.h"
#include "Irrigation/Irrigation_interface.h"
#include "../HAL/Buzzer/Buzzer_interface.h"
#include "../HAL/Button/Button_interface.h"
#include "../HAL/Fan/Fan_interface.h"
#include "../HAL/Humidity/Humidity_interface.h"
#include "../HAL/Ultrasonic/Ultrasonic_interface.h"
#include "../HAL/Motor/Motor_interface.h"
#include "../MCAL/ADC/ADC_interface.h"
#include "../MCAL/USART/USART_interface.h"

void main(void)
{
    u16 tick        = 0u;
    u8  lcd_page    = 0u;
    u8  current_mode = MODE_AUTO;
    u8  new_mode;
    u8  soil_pct = 0u;
    u8  humidity = 50u;
    u8  water_cm = 20u;
    u16 curr_mA  = 0u;

    /* ── Port config ── */
    ADCON1 = ADCON1_CONFIG;
    TRISA  = 0x07u;
    PORTB  = 0x00u;
    TRISB  = 0b00011011u;
    TRISC  = 0b10000000u;   /* RC7 = UART RX input */
    TRISD  = 0x00u;
    TRISE  = 0x00u;
    CLR_BIT(OPTION_REG, 7u);

    PORTD = portd_shadow;
    SET_BIT(PORTC, PIN_ENABLE);
    CLR_BIT(PORTC, PIN_TRIG);
    CLR_BIT(PORTC, PIN_DIR);
    CLR_BIT(PORTC, PIN_STEP);
    CLR_BIT(PORTC, PIN_FAN);
    SET_BIT(PORTC, 6u);         /* UART TX idle HIGH */
    CLR_BIT(PORTB, PIN_BUZZ);
    CLR_BIT(PORTE, PIN_LED_YLW);
    CLR_BIT(PORTE, PIN_LED_RED);

    /* ── Driver init ── */
    ADC_Init();
    UART_Init();
    LCD_Init();
    Safety_Init();
    Button_Init();
    Fan_Init();
    Humidity_Init();
    Buzzer_Init();

    LCD_GoToRowCol(1u, 1u); LCD_SendString_Const("Smart Irrigation");
    LCD_GoToRowCol(2u, 1u); LCD_SendString_Const(" Initializing...");
    { u8 s; for (s = 0u; s < 15u; s++) { __delay_ms(100); } }

    LCD_GoToRowCol(1u, 1u); LCD_SendString_Const("Waiting for Pi  ");
    LCD_GoToRowCol(2u, 1u); LCD_SendString_Const("                ");
    while (!Comms_HandshakeReceived()) { __delay_ms(100); Comms_Poll(); }
    Comms_SendHandshakeAck();

    LCD_GoToRowCol(1u, 1u); LCD_SendString_Const("Pi Ready!       ");
    LCD_GoToRowCol(2u, 1u); LCD_SendString_Const("Starting...     ");
    { u8 s; for (s = 0u; s < 15u; s++) { __delay_ms(100); } }
    LCD_Clear();

    Comms_SendStatus(MODE_AUTO, 0u);

    /* ── Main loop (1 tick = 100 ms) ── */
    while (1)
    {
        __delay_ms(100);
        tick++;

        Button_Poll();
        Comms_Poll();

        new_mode = Comms_GetMode();
        if (new_mode != current_mode)
        {
            u8 was_auto = (u8)(current_mode == MODE_AUTO);
            current_mode = new_mode;

            /* Force-stop any auto activity when leaving AUTO */
            if (was_auto && current_mode == MODE_MANUAL) {
                u8 pos = Motor_GetPositionCm();
                portd_shadow |= (u8)(1u << PIN_PUMP);
                PORTD = portd_shadow;
                LCD_GoToRowCol(1u, 1u);
                LCD_SendString_Const("AUTO->MAN at ");
                LCD_SendNumber((s16)pos);
                LCD_SendString_Const("cm");
                LCD_GoToRowCol(2u, 1u);
                LCD_SendString_Const("Homing...       ");
                Motor_Home();
                Motor_Disable();
                tick = 0u;
            }

            Comms_SendStatus(current_mode, Safety_IsLocked());
            LCD_GoToRowCol(2u, 1u);
            LCD_SendString_Const(current_mode == MODE_AUTO ? "Auto Mode OK    "
                                                            : "Manual Mode     ");
        }

        /* Estop edge — show pos, home, hold until released */
        if (Button_IsEstopped() || Comms_AppEstopActive())
        {
            u8 pos = Motor_GetPositionCm();
            portd_shadow |= (u8)(1u << PIN_PUMP);
            PORTD = portd_shadow;
            LCD_GoToRowCol(1u, 1u);
            LCD_SendString_Const("ESTOP at ");
            LCD_SendNumber((s16)pos);
            LCD_SendString_Const("cm   ");
            LCD_GoToRowCol(2u, 1u);
            LCD_SendString_Const("Home + wait     ");
            Motor_Home();
            Motor_Disable();
            while (Button_IsEstopped() || Comms_AppEstopActive()) {
                __delay_ms(100);
                Button_Poll();
                Comms_Poll();
            }
            LCD_GoToRowCol(2u, 1u);
            LCD_SendString_Const("Resumed         ");
            tick = 0u;
        }

        if (current_mode == MODE_MANUAL && Comms_ManualCommandPending())
        {
            u8 plant = Comms_GetManualPlant();
            Comms_ClearManualCommand();
            if (!Safety_IsLocked() && !Button_IsEstopped() && !Comms_AppEstopActive())
                Irrigation_RunSinglePlant(plant);
        }

        /* Manual pump on/off from app (esp/pump cmd via Pi) */
        if (current_mode == MODE_MANUAL && Comms_PumpCommandPending())
        {
            u8 pstate = Comms_GetPumpState();
            u8 pplant = Comms_GetPumpPlant();
            Comms_ClearPumpCommand();
            if (pstate == 0u) {
                Irrigation_PumpOff();
            } else if (!Safety_IsLocked() && !Button_IsEstopped() && !Comms_AppEstopActive()) {
                Irrigation_PumpOnAt(pplant);
            }
        }

        /* Safety override: kill pump if locked/estopped while manually on */
        if (Safety_IsLocked() || Button_IsEstopped() || Comms_AppEstopActive())
        {
            portd_shadow |= (u8)(1u << PIN_PUMP);
            PORTD = portd_shadow;
        }

        /* Sensor read every 2 s */
        if ((tick % SENSOR_PERIOD_TICKS) == 0u)
        {
            soil_pct = ADC_SoilPct(ADC_Read(ADC_CH_SOIL));
            curr_mA  = ADC_CurrentmA(ADC_Read(ADC_CH_CURRENT));
            water_cm = Ultrasonic_GetWaterLevel();
            Humidity_Read(&humidity, &last_temp_c);
            Safety_RunChecks(soil_pct, last_temp_c, curr_mA, water_cm);
            Comms_SendSensors(soil_pct, last_temp_c, humidity, curr_mA, water_cm);

            LCD_GoToRowCol(1u, 1u);
            switch (lcd_page % 5u)
            {
            case 0u: LCD_SendString_Const("Soil:"); LCD_SendNumber((s16)soil_pct); LCD_SendString_Const("%          "); break;
            case 1u: LCD_SendString_Const("Temp:"); LCD_SendNumber((s16)last_temp_c); LCD_SendString_Const("C          "); break;
            case 2u: LCD_SendString_Const("Hum :"); LCD_SendNumber((s16)humidity); LCD_SendString_Const("%          "); break;
            case 3u: LCD_SendString_Const("Curr:"); LCD_SendNumber((s16)curr_mA); LCD_SendString_Const("mA     "); break;
            case 4u: LCD_SendString_Const("Watr:"); LCD_SendNumber((s16)water_cm); LCD_SendString_Const("cm         "); break;
            default: break;
            }
            lcd_page++;

            if (!Safety_IsLocked())
            {
                LCD_GoToRowCol(2u, 1u);
                if (Button_IsEstopped() || Comms_AppEstopActive())
                    LCD_SendString_Const("E-STOP ACTIVE   ");
                else if (current_mode == MODE_MANUAL)
                    LCD_SendString_Const("Manual Mode     ");
                else
                    LCD_SendString_Const("Auto Mode OK    ");
            }
        }

        /* Irrigation every 5 min */
        if (current_mode == MODE_AUTO && tick >= IRRIG_PERIOD_TICKS)
        {
            tick = 0u;
            if (!Safety_IsLocked() && !Button_IsEstopped() && !Comms_AppEstopActive())
                Irrigation_RunCycle();
        }

        if (current_mode == MODE_MANUAL && tick >= IRRIG_PERIOD_TICKS)
            tick = 0u;
    }
}

#endif /* SECTION 1 — PRODUCTION MAIN */

/* ═══════════════════════════════════════════════════════════════════════════
   SECTION 2 — DEBUG MAIN  (active — flip to #if 0 when going to production)
   Verify full pipeline without 5-min timer or Pi handshake gate.
   Cycle: move 5 cm to plant → read all sensors → send to Pi → signal photo
          → Pi uploads to Firebase → next plant → … → bounce back → repeat.
   ═══════════════════════════════════════════════════════════════════════════ */
#if 1

#include "Comms/Comms_interface.h"
#include "../HAL/Button/Button_interface.h"
#include "../HAL/Motor/Motor_interface.h"
#include "../HAL/Humidity/Humidity_interface.h"
#include "../HAL/Ultrasonic/Ultrasonic_interface.h"
#include "../MCAL/ADC/ADC_interface.h"
#include "../MCAL/USART/USART_interface.h"

/* Time given to Pi to capture image and upload to Firebase */
#define PI_PHOTO_WAIT_TICKS 200u /* 200 × 100 ms = 20 s */

static u8 estop_now(void)
{
    Button_Poll();
    Comms_Poll();
    return (u8)(Button_IsEstopped() || Comms_AppEstopActive());
}

static void handle_estop(void)
{
    u8 pos_cm = Motor_GetPositionCm();

    LCD_Clear();
    LCD_GoToRowCol(1u, 1u);
    LCD_SendString_Const("E-STOP at ");
    LCD_SendNumber((s16)pos_cm);
    LCD_SendString_Const("cm   ");
    LCD_GoToRowCol(2u, 1u);
    LCD_SendString_Const("Stopping...     ");

    {
        u8 s;
        for (s = 0u; s < 10u; s++)
        {
            __delay_ms(100);
        }
    }

    LCD_GoToRowCol(2u, 1u);
    LCD_SendString_Const("Reset motor->0  ");
    Motor_Home();
    Motor_Disable();

    LCD_GoToRowCol(2u, 1u);
    LCD_SendString_Const("At home. Waiting");

    /* Wait until both estop sources clear (hw button toggle / app release) */
    while (1)
    {
        __delay_ms(100);
        Button_Poll();
        Comms_Poll();
        if (!Button_IsEstopped() && !Comms_AppEstopActive())
            break;
    }

    LCD_Clear();
    LCD_GoToRowCol(1u, 1u);
    LCD_SendString_Const("Resumed         ");
    {
        u8 s;
        for (s = 0u; s < 10u; s++)
        {
            __delay_ms(100);
        }
    }
}

/* Render row 1 with one of 5 sensor pages. Page cycles every PAGE_TICKS. */
#define PAGE_TICKS 40u /* 40 × 100 ms = 4 s per page → 5 pages in 20 s */

static void render_sensor_page(u8 plant_idx, u8 page,
                               u8 soil, u8 temp, u8 hum, u16 curr, u8 water)
{
    LCD_GoToRowCol(1u, 1u);
    LCD_SendString_Const("P");
    LCD_SendNumber((s16)plant_idx);
    LCD_SendString_Const(" ");
    switch (page % 5u)
    {
    case 0u:
        LCD_SendString_Const("Soil:");
        LCD_SendNumber((s16)soil);
        LCD_SendString_Const("%        ");
        break;
    case 1u:
        LCD_SendString_Const("Temp:");
        LCD_SendNumber((s16)temp);
        LCD_SendString_Const("C        ");
        break;
    case 2u:
        LCD_SendString_Const("Hum:");
        LCD_SendNumber((s16)hum);
        LCD_SendString_Const("%         ");
        break;
    case 3u:
        LCD_SendString_Const("Cur:");
        LCD_SendNumber((s16)curr);
        LCD_SendString_Const("mA     ");
        break;
    case 4u:
        LCD_SendString_Const("Wtr:");
        LCD_SendNumber((s16)water);
        LCD_SendString_Const("cm        ");
        break;
    default:
        break;
    }
}

static void read_and_signal(u8 plant_idx)
{
    u8 soil, humidity, water;
    u16 curr;
    u8 t, page = 0u;

    soil = ADC_SoilPct(ADC_Read(ADC_CH_SOIL));
    curr = ADC_CurrentmA(ADC_Read(ADC_CH_CURRENT));
    water = Ultrasonic_GetWaterLevel();
    Humidity_Read(&humidity, &last_temp_c);

    /* Send sensor packet then trigger Pi camera */
    Comms_SendSensors(soil, last_temp_c, humidity, curr, water);
    Comms_SendAtPlant(plant_idx);

    LCD_GoToRowCol(2u, 1u);
    LCD_SendString_Const("Pi: uploading...");

    render_sensor_page(plant_idx, page, soil, last_temp_c, humidity, curr, water);

    for (t = 0u; t < PI_PHOTO_WAIT_TICKS; t++)
    {
        __delay_ms(100);
        if (estop_now())
        {
            handle_estop();
            return;
        }
        if (((t + 1u) % PAGE_TICKS) == 0u)
        {
            page++;
            render_sensor_page(plant_idx, page, soil, last_temp_c,
                               humidity, curr, water);
        }
    }
}

void main(void)
{
    /* plant_idx alternates 0 → 1 → 0 → 1 … bouncing between both plants */
    u8 plant_idx = 0u;

    /* ── Port config ── */
    ADCON1 = ADCON1_CONFIG;
    TRISA = 0x07u;
    PORTB = 0x00u;
    TRISB = 0b00011011u;
    TRISC = 0b10000000u; /* RC7 = UART RX input */
    TRISD = 0x00u;
    TRISE = 0x00u;
    CLR_BIT(OPTION_REG, 7u);

    PORTD = portd_shadow;
    SET_BIT(PORTC, PIN_ENABLE);
    CLR_BIT(PORTC, PIN_TRIG);
    CLR_BIT(PORTC, PIN_DIR);
    CLR_BIT(PORTC, PIN_STEP);
    CLR_BIT(PORTC, PIN_FAN);
    SET_BIT(PORTC, 6u); /* UART TX idle HIGH */
    CLR_BIT(PORTB, PIN_BUZZ);
    CLR_BIT(PORTE, PIN_LED_YLW);
    CLR_BIT(PORTE, PIN_LED_RED);

    ADC_Init();
    UART_Init();
    LCD_Init();
    Button_Init();
    Humidity_Init();
    Motor_Init();

    LCD_GoToRowCol(1u, 1u);
    LCD_SendString_Const("Debug: Sense+   ");
    LCD_GoToRowCol(2u, 1u);
    LCD_SendString_Const("Photo Pipeline  ");
    {
        u8 s;
        for (s = 0u; s < 20u; s++)
        {
            __delay_ms(100);
        }
    } /* 2 s splash */

    while (1)
    {
        /* Estop check before move */
        if (estop_now())
        {
            handle_estop();
            plant_idx = 0u;
            continue;
        }

        /* Move to next plant. P0 = 3 cm from home, P1 = 13 cm (10 cm apart) */
        LCD_GoToRowCol(1u, 1u);
        LCD_SendString_Const("Moving -> P");
        LCD_SendNumber((s16)plant_idx);
        LCD_SendString_Const("    ");
        LCD_GoToRowCol(2u, 1u);
        LCD_SendString_Const(plant_idx == 0u ? "to 3cm          "
                                             : "to 13cm         ");

        Motor_MoveTo(plant_idx);
        Motor_Disable();

        if (estop_now())
        {
            handle_estop();
            plant_idx = 0u;
            continue;
        }

        /* Read sensors, send to Pi, signal photo, wait for upload */
        read_and_signal(plant_idx);

        /* Bounce: 0 → 1 → 0 → 1 … */
        plant_idx ^= 1u;
    }
}

#endif /* SECTION 2 — DEBUG MAIN */

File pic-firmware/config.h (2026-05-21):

/*
 * config.h
 * Smart Irrigation — Central Configuration
 * Include FIRST in every .c file, before <xc.h>, so _XTAL_FREQ is
 * defined before any __delay_ms / __delay_us macro is encountered.
 *
 * Hardware: PIC16F877A @ 8 MHz external crystal
 * Compiler: XC8 v2.36 free mode
 */

#ifndef CONFIG_H
#define CONFIG_H

/* ================================================================
   CRYSTAL / COMPILER
   ================================================================ */
#define _XTAL_FREQ 8000000UL /* Required by __delay_ms/__delay_us */

/* ================================================================
   OPERATING MODES
   ================================================================ */
#define MODE_AUTO 0u
#define MODE_MANUAL 1u

/* ================================================================
   UART / COMMS PROTOCOL
   ================================================================ */
#define UART_SPBRG_VAL 51u /* 9600 baud @ 8MHz, BRGH=1: (8MHz/153600)-1 */

#define UART_HDR_PI_TO_PIC 0xBBu /* Header byte: Pi → PIC packets             */
#define UART_HDR_PIC_TO_PI 0xAAu /* Header byte: PIC → Pi packets             */

/* Pi → PIC command bytes (3-byte packet: [0xBB][CMD][DATA]) */
#define UART_CMD_MODE 0x01u      /* DATA: 0x00=auto, 0x01=manual              */
#define UART_CMD_IRRIGATE 0x02u  /* DATA: 0x00–0x04 plant index               */
#define UART_CMD_ESTOP 0x03u     /* DATA: 0x01=stop, 0x00=release             */
#define UART_CMD_PUMP 0x04u      /* DATA: high nibble=plant(0/1), low=state(0=OFF,1=ON) */
#define UART_CMD_HANDSHAKE 0x10u /* DATA: 0xAA — Pi signals ready             */

/* PIC → Pi type bytes (variable packet: [0xAA][TYPE][DATA...]) */
#define UART_TYPE_SENSORS 0x01u   /* 6 data bytes: soil,temp,hum,curr_h,curr_l,water */
#define UART_TYPE_AT_PLANT 0x02u  /* 1 data byte:  plant_index — "take image now"    */
#define UART_TYPE_STATUS 0x03u    /* 2 data bytes: mode, lockout                     */
#define UART_TYPE_HANDSHAKE 0x10u /* 1 data byte:  0xBB — PIC handshake ACK          */

/* ================================================================
   ADC
   ================================================================ */
#define ADCON1_CONFIG 0x84u /* ADFM=1 right-just; PCFG=0100: AN0-AN2 analog, RE1/RE2 digital */
#define ADC_CH_SOIL 0u      /* AN0 / RA0 — capacitive soil moisture sensor   */
#define ADC_CH_CURRENT 2u   /* AN2 / RA2 — ACS712-05B current sensor         */

/* Soil moisture sensor calibration (capacitive v1.2):
   Dry  ≈ 3.0 V → ADC raw ≈ 614
   Wet  ≈ 1.2 V → ADC raw ≈ 245
   Formula: pct = 100 - ((raw - WET_ADC) * 100 / (DRY_ADC - WET_ADC)), clamped 0-100 */
#define DRY_ADC 614u
#define WET_ADC 245u

/* ================================================================
   SAFETY THRESHOLDS
   ================================================================ */

/* Overwatering (soil moisture %) */
#define SOIL_WARN_PCT 80u   /* Warning:  amber LED + beep                    */
#define SOIL_ACTION_PCT 90u /* Action:   red LED + pump OFF + lockout        */
#define SOIL_CLEAR_PCT 75u  /* Hysteresis clear level                        */
#define SOIL_SKIP_PCT 70u   /* Irrigation skip: soil already wet enough      */

/* Overheat (DHT11 temperature °C, integer resolution) */
#define TEMP_WARN_C 55u   /* Warning:  amber LED + beep + fan ON           */
#define TEMP_ACTION_C 70u /* Action:   red LED + shutdown + lockout + fan  */
#define TEMP_CLEAR_C 50u  /* Hysteresis clear level (fan OFF when clear)   */

/* Overcurrent (ACS712-05B, milliamps) */
#define CURR_WARN_MA 3500u   /* Warning:  amber LED + beep                   */
#define CURR_ACTION_MA 4500u /* Action:   red LED + pump+stepper OFF + lockout */
#define CURR_CLEAR_MA 3000u  /* Hysteresis clear level                        */

/* Dry-run / low water (HC-SR04, cm from top of tank) */
#define WATER_WARN_CM 5u   /* Warning:  amber LED + beep                   */
#define WATER_ACTION_CM 2u /* Action:   red LED + pump OFF + lockout        */
#define WATER_CLEAR_CM 6u  /* Hysteresis clear level                        */
#define TANK_HEIGHT_CM 30u /* Physical tank height — used in distance→level */

/* ================================================================
   IRRIGATION
   ================================================================ */
#define NUM_PLANTS 2u             /* Number of plant positions on gantry       */
#define PUMP_ON_TICKS 50u         /* Pump-on duration: 50 × 100ms = 5 s        */
#define SETTLE_MS_LOOP 3u         /* Post-move settle: 3 × __delay_ms(100)     */
#define HOMING_BACKOFF_STEPS 200u /* Steps to back off after limit switch hit  */

/* Plant positions in microsteps from home (GT2 20T pulley, 1/16 microstepping):
   1 step = 0.0125 mm → 100 mm = 8000 steps; first plant at 50 mm = 4000 steps  */
/* Array defined in motor.c:
   const u32 plant_positions[NUM_PLANTS] = {4000, 12000, 20000, 28000, 36000};  */
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

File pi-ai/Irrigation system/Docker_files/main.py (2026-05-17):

#!/usr/bin/env python3
"""
AI-Actuation Loop — 50 runs with real TFLite inference
Logs success rate, class predictions, confidence, and UART packets.
"""

import json
import time
import numpy as np
from pathlib import Path
from PIL import Image
import tflite_runtime.interpreter as tflite

# ─── CONFIG ──────────────────────────────────────────────────────────────────
MODEL_PATH      = "model.tflite"
CLASS_NAMES_PATH = "class_names.json"
SAMPLE_IMAGES   = "results/sample_images.png"  # fallback if no real images
RUNS            = 50
INPUT_SIZE      = 224

PROTOCOL_MAP = {
    "healthy":             0x01,
    "early_blight":        0x02,
    "late_blight":         0x03,
    "pest":                0x04,
    "nutrient_deficiency": 0x05,
    "unknown":             0xFF,
}

CONFIDENCE_THRESHOLDS = {
    "healthy":             0.90,
    "early_blight":        0.80,
    "late_blight":         0.75,
    "pest":                0.70,
    "nutrient_deficiency": 0.75,
}

START_BYTE = 0xBB
END_BYTE   = 0xEE

# ─── LOAD CLASS NAMES ────────────────────────────────────────────────────────
with open(CLASS_NAMES_PATH) as f:
    CLASS_NAMES = json.load(f)

# ─── LOAD MODEL ──────────────────────────────────────────────────────────────
interpreter = tflite.Interpreter(model_path=MODEL_PATH)
interpreter.allocate_tensors()
input_details  = interpreter.get_input_details()
output_details = interpreter.get_output_details()

print(f"✅ Model loaded: {MODEL_PATH}")
print(f"✅ Classes: {CLASS_NAMES}")

# ─── HELPERS ─────────────────────────────────────────────────────────────────
def preprocess(image_path: str) -> np.ndarray:
    img = Image.open(image_path).convert("RGB").resize((INPUT_SIZE, INPUT_SIZE))
    arr = np.array(img, dtype=np.float32)
    scale, zero_point = input_details[0]['quantization']
    if scale != 0:
        arr = (arr / scale + zero_point).astype(np.int8)
    else:
        arr = arr.astype(np.float32) / 255.0
    return np.expand_dims(arr, axis=0)

def run_inference(image_path: str):
    input_data = preprocess(image_path)
    interpreter.set_tensor(input_details[0]['index'], input_data)

    t0 = time.monotonic()
    interpreter.invoke()
    inference_ms = (time.monotonic() - t0) * 1000

    output = interpreter.get_tensor(output_details[0]['index'])

    if output_details[0]['dtype'] in (np.uint8, np.int8):
        scale, zero_point = output_details[0]['quantization']
        output = (output.astype(np.float32) - zero_point) * scale

    probs = output[0]
    if np.any(probs < 0) or not (0.99 <= np.sum(probs) <= 1.01):
        exp_p = np.exp(probs - np.max(probs))
        probs = exp_p / np.sum(exp_p)

    class_idx  = int(np.argmax(probs))
    confidence = float(probs[class_idx])
    class_name = CLASS_NAMES[class_idx] if class_idx < len(CLASS_NAMES) else "unknown"

    return class_name, confidence, inference_ms

def build_uart_packet(protocol_id: int, zone_x: int = 0x80) -> bytes:
    param_map = {
        0x01: (0,   1),
        0x02: (60,  1),
        0x03: (0,   1),
        0x04: (3,   6),
        0x05: (130, 1),
        0xFF: (0,   1),
    }
    param1, param2 = param_map.get(protocol_id, (0, 1))
    zone_y  = 0x00
    payload = bytes([START_BYTE, protocol_id, zone_x, zone_y, param1, param2])
    crc     = 0
    for b in payload[1:]:
        crc ^= b
    return payload + bytes([crc & 0xFF, END_BYTE])

# ─── FIND TEST IMAGES ────────────────────────────────────────────────────────
image_files = [Path("test.jpg")]

if not image_files:
    print("⚠️  No images found! Put some leaf images in the project folder.")
    exit(1)

print(f"📸 Found {len(image_files)} images for testing")

# ─── MAIN LOOP ───────────────────────────────────────────────────────────────
logs        = []
success     = 0
total_ms    = 0

print(f"\n🔁 Running {RUNS} inference loops...\n")

for i in range(RUNS):
    # cycle through available images
    img_path = str(image_files[i % len(image_files)])

    t_start = time.monotonic()

    predicted_class, confidence, inference_ms = run_inference(img_path)
    total_ms += inference_ms

    # Check threshold (normalize to lowercase for lookup)
    threshold = CONFIDENCE_THRESHOLDS.get(predicted_class.lower(), 0.70)
    if confidence < threshold:
        predicted_class = "unknown"

    protocol_id = PROTOCOL_MAP.get(predicted_class.lower(), 0xFF)
    packet      = build_uart_packet(protocol_id)

    latency_ms = (time.monotonic() - t_start) * 1000

    if predicted_class != "unknown":
        success += 1

    run_data = {
        "run":          i + 1,
        "image":        img_path,
        "class":        predicted_class,
        "confidence":   round(confidence, 4),
        "protocol":     f"0x{protocol_id:02X}",
        "uart_packet":  packet.hex(),
        "inference_ms": round(inference_ms, 1),
        "latency_ms":   round(latency_ms, 1),
    }
    logs.append(run_data)

    print(
        f"[{i+1:02d}/50] {predicted_class:<20} "
        f"conf={confidence:.2%}  "
        f"proto=0x{protocol_id:02X}  "
        f"infer={inference_ms:.0f}ms"
    )

# ─── RESULTS ─────────────────────────────────────────────────────────────────
success_rate = success / RUNS
avg_ms       = total_ms / RUNS

print(f"\n{'='*55}")
print(f"✅ Success Rate   : {success_rate:.2%} ({success}/{RUNS})")
print(f"⚡ Avg Inference  : {avg_ms:.1f}ms")
print(f"🎯 Target         : >95% success, <200ms inference")
print(f"{'='*55}\n")

# Save logs
Path("results").mkdir(exist_ok=True)
with open("results/run_logs.json", "w") as f:
    json.dump({
        "summary": {
            "success_rate": round(success_rate, 4),
            "successful_runs": success,
            "total_runs": RUNS,
            "avg_inference_ms": round(avg_ms, 1),
        },
        "runs": logs
    }, f, indent=4)

print("📄 Logs saved to results/run_logs.json")

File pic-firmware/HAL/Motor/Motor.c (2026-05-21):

/*
 * Motor.c
 * A4988 stepper driver, 1/16 microstepping.
 * RC0=STEP, RC1=DIR (HIGH=away from home), RC2=ENABLE (LOW=on).
 * RB3=limit switch (active LOW) marks home position.
 * Motor relay (RD1) removed — single-channel relay board, pump only.
 *
 * Speed note: __delay_us() with a compile-time constant generates an
 * efficient NOP loop. The old variable-loop approach had ~5-10x overhead
 * in XC8 free mode, making 500 "µs" delays actually ~5 ms.
 * Two inline functions (normal / homing) with fixed delays fix this.
 */

#include "../../config.h"
#include "Motor_interface.h"
#include "../Button/Button_interface.h"
#include "../../APP/Comms/Comms_interface.h"
#include "../../MCAL/MCU_Registers.h"
#include "../../SERVICES/BIT_MATH.h"
#include "../../SERVICES/STD_TYPES.h"

#define STEPS_PER_CM 800u

static s32 current_position = 0;

/* 2 plants. 1 step = 0.0125 mm → 1 cm = 800 steps.
   Plant 0:  2400 steps (3  cm from home)
   Plant 1: 10400 steps (13 cm from home, 10 cm gap)  */
static const u32 plant_positions[NUM_PLANTS] = {2400u, 10400u};

void Motor_Init(void)
{
    CLR_BIT(PORTC, PIN_STEP);
    CLR_BIT(PORTC, PIN_DIR);
    SET_BIT(PORTC, PIN_ENABLE); /* A4988 disabled at startup */
    current_position = 0;
}

/* Compile-time constant delays — efficient NOP loops, no loop overhead.
   Tune STEP_DELAY_NORMAL_US / STEP_DELAY_HOMING_US in config.h.
   At 8 MHz: max reliable speed with NEMA17 + no load ≈ 200 µs/step.
   Add 100 µF + 100 nF caps on VMOT-GND for stability above 500 steps/s. */
static void step_once_normal(void)
{
    SET_BIT(PORTC, PIN_STEP);
    __delay_us(2);
    CLR_BIT(PORTC, PIN_STEP);
    __delay_us(STEP_DELAY_NORMAL_US);
}

static void step_once_homing(void)
{
    SET_BIT(PORTC, PIN_STEP);
    __delay_us(2);
    CLR_BIT(PORTC, PIN_STEP);
    __delay_us(STEP_DELAY_HOMING_US);
}

void Motor_Home(void)
{
    u32 backoff;
    u16 poll_cnt = 0u;

    CLR_BIT(PORTC, PIN_ENABLE); /* enable A4988 */
    CLR_BIT(PORTC, PIN_DIR);    /* DIR LOW = toward home */

    while (GET_BIT(PORTB, PIN_LIMIT))
    {
        step_once_homing();
        poll_cnt++;
        if ((poll_cnt & 0x31u) == 0u)
        {
            Button_Poll();
            if (Button_IsEstopped())
            {
                Motor_Disable();
                return;
            }
        }
    }

    /* Back off from limit switch */
    SET_BIT(PORTC, PIN_DIR);
    for (backoff = 0u; backoff < HOMING_BACKOFF_STEPS; backoff++)
    {
        step_once_homing();
    }

    current_position = 0;
    CLR_BIT(PORTC, PIN_DIR);
}

void Motor_MoveTo(u8 plant_index)
{
    s32 target, delta;
    u32 steps;
    u16 poll_cnt = 0u;

    if (plant_index >= NUM_PLANTS)
        return;

    target = (s32)plant_positions[plant_index];
    delta = target - current_position;
    steps = (delta < 0) ? (u32)(-delta) : (u32)delta;

    CLR_BIT(PORTC, PIN_ENABLE);

    if (delta > 0)
        SET_BIT(PORTC, PIN_DIR);
    else
        CLR_BIT(PORTC, PIN_DIR);

    while (steps > 0u)
    {
        step_once_normal();
        steps--;
        current_position += (delta > 0) ? 1 : -1;
        poll_cnt++;
        if ((poll_cnt % 25u) == 0u)
        {
            Button_Poll();
            Comms_Poll();
            if (Button_IsEstopped() || Comms_AppEstopActive())
            {
                Motor_Disable();
                return;
            }
        }
    }
}

void Motor_Disable(void)
{
    SET_BIT(PORTC, PIN_ENABLE); /* A4988 ENABLE HIGH = free shaft */
}

u8 Motor_GetPositionCm(void)
{
    s32 p = current_position;
    if (p < 0)
        p = -p;
    return (u8)(((u32)p + (STEPS_PER_CM / 2u)) / STEPS_PER_CM);
}

s32 Motor_GetPositionSteps(void)
{
    return current_position;
}

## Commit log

2026-04-23 Initial Drivers
2026-05-21 Update README and ESP8266 firmware for pump actuator integration
    - Revised README to clarify actuator topology and control paths for the pump.
    - Added detailed description of the ESP8266 NodeMCU's role and functionality.
    - Introduced a template for secrets management in esp-firmware to enhance security practices.
